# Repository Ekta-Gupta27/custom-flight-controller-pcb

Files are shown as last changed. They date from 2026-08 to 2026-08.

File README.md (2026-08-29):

# Custom Flight Controller PCB

A custom-designed flight controller PCB developed for embedded flight-control applications, integrating a high-performance STM32 MCU, multiple inertial and pressure sensors, CAN communication, external flash memory, power management, and dedicated FMU/IO interfaces.

The PCB and schematic were designed using **KiCad 9.0.7**.

---

## 📌 Project Overview

This project focuses on the design and development of a custom flight controller PCB with dedicated interfaces for sensors, communication peripherals, power, debugging, telemetry, PWM outputs, and RC input/output.

The design is divided into multiple functional sections:

- Main Flight Management Unit (FMU)
- IO controller
- IMU and pressure sensing
- CAN communication
- USB connectivity
- External SPI flash memory
- Power regulation
- Telemetry interfaces
- PWM and RC interfaces
- Debug/programming interfaces

---

## ✨ Key Features

- Custom PCB designed from schematic to board layout
- STM32F765VITx main flight controller MCU
- STM32F103CBTx dedicated IO controller
- Multiple onboard sensors
- CAN communication interface
- USB OTG interface
- External SPI flash memory
- Multiple UART interfaces
- I2C and SPI interfaces
- PWM output interface
- SBUS and PPM interfaces
- Debug/programming interface
- Dedicated GPS and telemetry connectors
- Onboard status/safety LEDs
- 3.3 V and 5 V power domains
- Multi-layer PCB layout
- Manufacturing-ready Gerber and drill files

---

## 🧠 Hardware Architecture

### Main Flight Controller

The primary processing unit is an **STM32F765VITx**.

The MCU provides the main processing and peripheral interfaces for the flight-control system, including:

- SPI
- I2C
- UART
- CAN
- Timer/PWM channels
- SWD debugging
- External GPIO

### IO Controller

A dedicated **STM32F103CBTx** is used for the IO section of the design.

The IO controller provides interfaces for:

- SBUS
- PPM
- PWM
- RC input/output
- Safety signals
- Status LEDs
- Debugging
- Additional UART interfaces

---

## 📡 Sensors

The design incorporates multiple sensors:

### ICM-42688-P

6-axis inertial measurement sensor connected through SPI.

### BMI270

6-axis inertial sensor with dedicated interrupt and SPI connections.

### ICP-20100

Pressure sensor connected through the I2C interface.

### BMM150

Magnetic sensor connected through the I2C interface.

---

## 🔌 Communication Interfaces

### CAN

CAN communication is implemented using the **SN65HVD230** transceiver with dedicated CANH and CANL connections and protection circuitry.

### USB

A USB OTG interface is provided along with USB ESD protection using **USBLC6-2P6**.

### UART / Telemetry

Dedicated connectors are provided for:

- TELEM1
- TELEM2
- TELEM3
- UART/I2C interface
- GPS
- FMU communication

### I2C

Multiple I2C buses are available for sensor and peripheral communication.

### SPI

Multiple SPI buses are routed to sensors, flash memory, and external interfaces.

---

## 💾 External Flash Memory

The board includes external SPI flash memory:

**W25Q128JVS**

The flash device is connected to the main MCU through SPI with a dedicated chip-select signal.

---

## ⚡ Power Management

The PCB contains dedicated power regulation and filtering circuitry for the different system power domains.

The design includes:

- 5 V input
- 3.3 V regulation
- USB 5 V input
- External 3.3 V supply
- Decoupling capacitors
- Ferrite filtering
- Power indication circuitry

The schematic includes regulators such as:

- LM1117DT-3.3
- TLV75733PDBVR

---

## 🎛️ Interfaces & Connectors

| Interface | Purpose |
|---|---|
| GPS_PORT | GPS connectivity |
| POWER | Power input |
| TELEM1 | Telemetry |
| TELEM2 | Telemetry |
| TELEM3 | Telemetry |
| CAN_CONN | CAN communication |
| USB_OTG | USB connectivity |
| DEBUG | Debug/programming |
| SPI_PORT | External SPI interface |
| I2C_PORT | External I2C interface |
| UART_I2CB | UART/I2C interface |
| FMU_PWM | PWM outputs |
| IO_PWM | IO PWM interface |
| SBUS_PORT | SBUS interface |
| SBUS_IN | SBUS input |
| PPM_PORT | PPM input |
| IO_DEBUG | IO debugging |

---

# 🖥️ PCB Design

## 3D View – Top

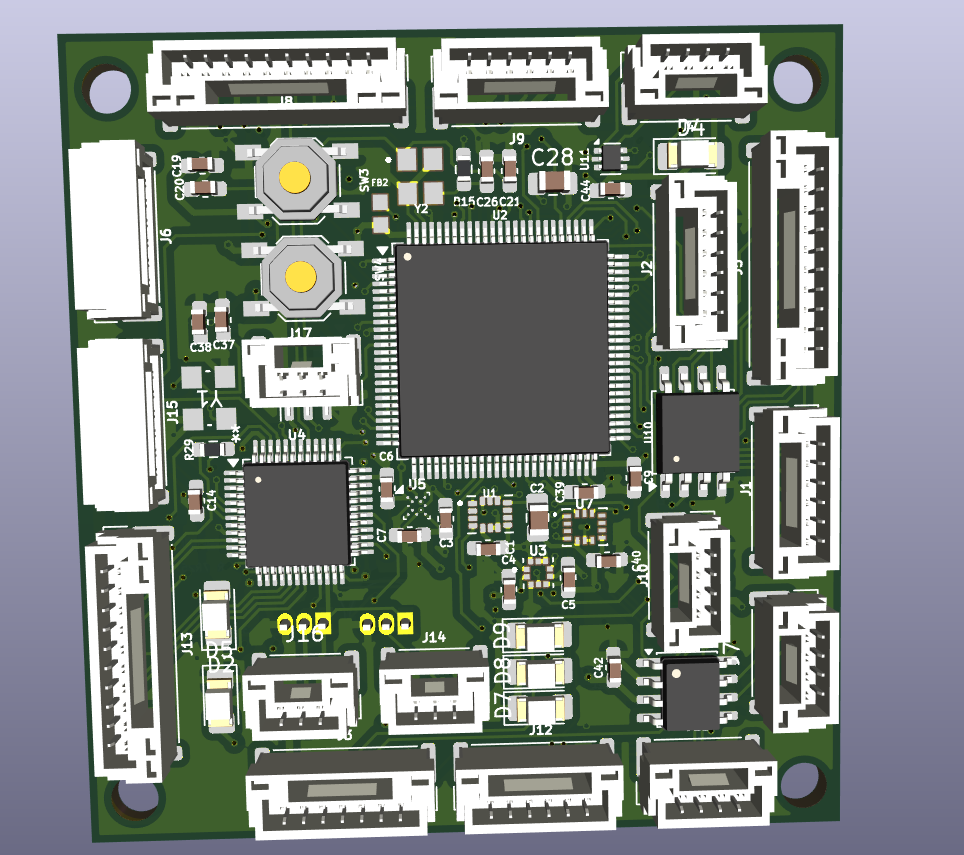
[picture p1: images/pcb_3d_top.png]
PCB 3D Top


## 3D View – Bottom

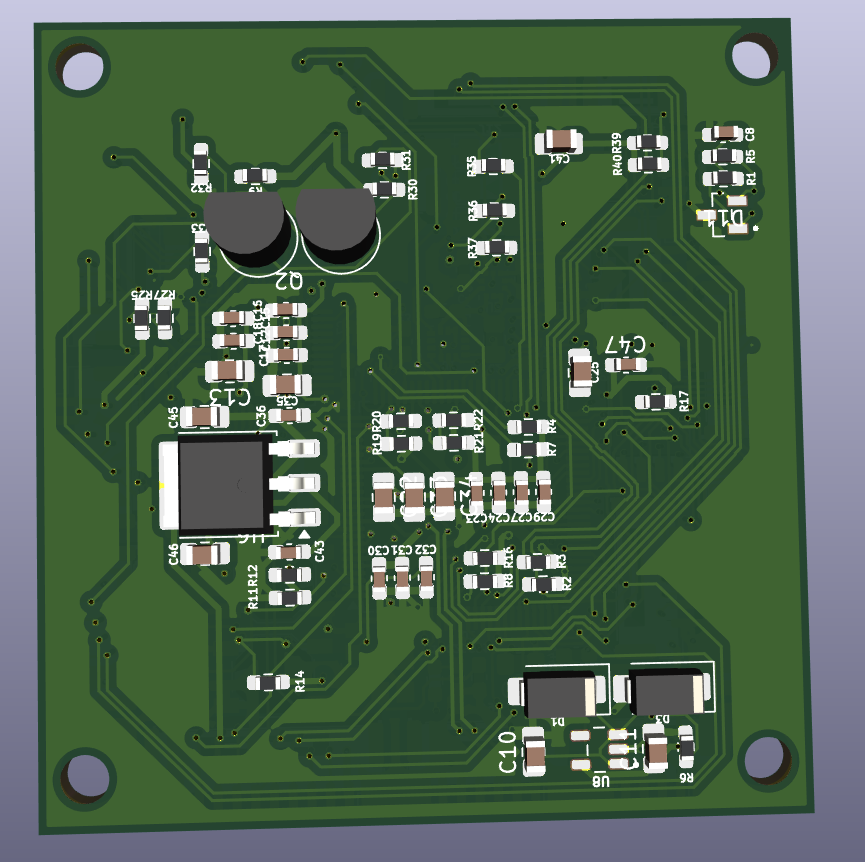
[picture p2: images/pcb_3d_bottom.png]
PCB 3D Bottom


## PCB Layout

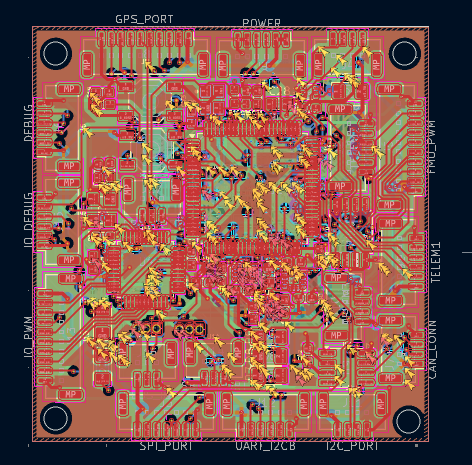
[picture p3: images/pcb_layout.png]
PCB Layout


---

# 📐 Schematic

The complete schematic is provided as a multi-page KiCad schematic covering:

1. FMU / MCU power and peripherals
2. USB and CAN
3. IMU and sensor interfaces
4. IO controller
5. Safety, RC and PWM interfaces

The PDF version is available in:

`docs/schematic.pdf`

---

# 🏭 Manufacturing Files

The `gerbers/` directory contains the manufacturing outputs generated from KiCad, including:

- Front and back copper
- Inner copper layers
- Front and back solder mask
- Front and back silkscreen
- Paste layers
- Board outline
- Drill files
- Gerber job file

These files can be supplied to a PCB manufacturer for fabrication.

---

# 📦 Bill of Materials

A Bill of Materials generated from the KiCad schematic is included in:

`manufacturing/BOM.csv`

The BOM contains information such as:

- Reference designators
- Component quantity
- Component value
- PCB footprint
- Datasheet information
- BOM exclusion fields

---

# 📁 Repository Structure

```text
Custom-FC-RAT/
│
├── README.md
├── custom_fc_rat.kicad_pro
│
├── schematic/
│   └── custom_fc_rat.kicad_sch
│
├── pcb/
│   └── custom_fc_rat.kicad_pcb
│
├── gerbers/
│   ├── *.gbl
│   ├── *.gtl
│   ├── *.gbs
│   ├── *.gts
│   ├── *.gbo
│   ├── *.gto
│   ├── *.gm1
│   ├── *.g1
│   ├── *.g2
│   ├── *.g3
│   ├── *.g4
│   ├── *.drl
│   └── *.gbrjob
│
├── manufacturing/
│   └── BOM.csv
│
├── images/
│   ├── pcb_3d_top.png
│   ├── pcb_3d_bottom.png
│   └── pcb_layout.png
│
└── docs/
    └── schematic.pdf
```

---

# 🛠️ Design Tools

| Tool | Purpose |
|---|---|
| KiCad 9.0.7 | Schematic & PCB design |
| KiCad 3D Viewer | PCB visualization |
| KiCad Gerber Generator | Manufacturing file generation |

---

# 🚀 Future Improvements

Possible future development includes:

- Hardware validation and bring-up documentation
- Flight-controller firmware integration
- Sensor calibration and validation
- Power integrity testing
- Communication interface testing
- EMI/EMC validation
- Flight testing
- PCB revisions based on hardware testing

---

# 📄 Documentation

The editable KiCad design files and schematic PDF are included so that the hardware design can be inspected and further developed.

---

# 👩‍💻 Author

**Ekta Gupta**

Custom PCB / Flight Controller Design Project

---

## ⭐ Project Status

**Hardware Design Completed**

Schematic, PCB layout, 3D visualization, BOM, and manufacturing files are included in this repository.

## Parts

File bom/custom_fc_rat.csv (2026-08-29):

Reference | Qty | Value | DNP | Exclude from BOM | Exclude from Board | Footprint | Datasheet
C1,C4,C5,C6,C7,C9,C12,C14,C15,C16,C17,C18,C19,C20,C23,C24,C27,C29,C30,C31,C32,C36,C39,C40,C42,C43,C44 | 27 | 0.1u |  |  |  | Capacitor_SMD:C_0603_1608Metric_Pad1.08x0.95mm_HandSolder | ~
C2,C10,C11 | 3 | 2.2u |  |  |  | Capacitor_SMD:C_0805_2012Metric_Pad1.18x1.45mm_HandSolder | ~
C3 | 1 | 10n |  |  |  | Capacitor_SMD:C_0603_1608Metric_Pad1.08x0.95mm_HandSolder | ~
C8 | 1 | 4.7n |  |  |  | Capacitor_SMD:C_0603_1608Metric_Pad1.08x0.95mm_HandSolder | ~
C13,C33,C34,C41 | 4 | 1u |  |  |  | Capacitor_SMD:C_0805_2012Metric_Pad1.18x1.45mm_HandSolder | ~
C21,C26 | 2 | 8pF |  |  |  | Capacitor_SMD:C_0603_1608Metric_Pad1.08x0.95mm_HandSolder | ~
C22,C35,C45,C46 | 4 | 10u |  |  |  | Capacitor_SMD:C_0805_2012Metric_Pad1.18x1.45mm_HandSolder | ~
C25,C28 | 2 | 2u2 |  |  |  | Capacitor_SMD:C_0805_2012Metric_Pad1.18x1.45mm_HandSolder | ~
C37,C38 | 2 | 18pF |  |  |  | Capacitor_SMD:C_0603_1608Metric_Pad1.08x0.95mm_HandSolder | ~
C47 | 1 | 1u |  |  |  | Capacitor_SMD:C_0603_1608Metric_Pad1.08x0.95mm_HandSolder | ~
D1,D3 | 2 | SS34 |  |  |  | Diode_SMD:D_SMA | https://www.vishay.com/docs/88751/ss32.pdf
D2,D4,D5,D7,D8,D9 | 6 | LED |  |  |  | LED_SMD:LED_1206_3216Metric_Pad1.42x1.75mm_HandSolder | ~
D11 | 1 | ESD2CANFD24DBZRQ1 |  |  |  | My_Footprints:SOT95P237X112-3N
FB2 | 1 | FerriteBead |  |  |  | My_Footprints:BEADC1608X95N | ~
J1 | 1 | TELEM1 |  |  |  | Connector_JST:JST_GH_BM06B-GHS-TBT_1x06-1MP_P1.25mm_Vertical | ~
J2 | 1 | TELEM2 |  |  |  | Connector_JST:JST_GH_BM06B-GHS-TBT_1x06-1MP_P1.25mm_Vertical | ~
J3 | 1 | SPI_PORT |  |  |  | Connector_JST:JST_GH_BM07B-GHS-TBT_1x07-1MP_P1.25mm_Vertical | ~
J4 | 1 | USB_OTG |  |  |  | Connector_JST:JST_GH_BM04B-GHS-TBT_1x04-1MP_P1.25mm_Vertical | ~
J5 | 1 | FMU_PWM |  |  |  | Connector_JST:JST_GH_BM10B-GHS-TBT_1x10-1MP_P1.25mm_Vertical | ~
J6 | 1 | DEBUG |  |  |  | Connector_JST:JST_GH_SM06B-GHS-TB_1x06-1MP_P1.25mm_Horizontal | ~
J7 | 1 | CAN_CONN |  |  |  | Connector_JST:JST_GH_BM04B-GHS-TBT_1x04-1MP_P1.25mm_Vertical | ~
J8 | 1 | GPS_PORT |  |  |  | Connector_JST:JST_GH_BM10B-GHS-TBT_1x10-1MP_P1.25mm_Vertical | ~
J9 | 1 | POWER |  |  |  | Connector_JST:JST_GH_BM06B-GHS-TBT_1x06-1MP_P1.25mm_Vertical | ~
J10 | 1 | TELEM3 |  |  |  | Connector_JST:JST_GH_BM04B-GHS-TBT_1x04-1MP_P1.25mm_Vertical | ~
J11 | 1 | I2C_PORT |  |  |  | Connector_JST:JST_GH_BM04B-GHS-TBT_1x04-1MP_P1.25mm_Vertical | ~
J12 | 1 | UART_I2CB |  |  |  | Connector_JST:JST_GH_BM06B-GHS-TBT_1x06-1MP_P1.25mm_Vertical | ~
J13 | 1 | IO_PWM |  |  |  | Connector_JST:JST_GH_BM10B-GHS-TBT_1x10-1MP_P1.25mm_Vertical | ~
J14 | 1 | SBUS_PORT |  |  |  | Connector_JST:JST_GH_BM03B-GHS-TBT_1x03-1MP_P1.25mm_Vertical | ~
J15 | 1 | IO_DEBUG |  |  |  | Connector_JST:JST_GH_SM06B-GHS-TB_1x06-1MP_P1.25mm_Horizontal | ~
J16 | 1 | SBUS_IN |  |  |  | Connector_JST:JST_GH_SM03B-GHS-TB_1x03-1MP_P1.25mm_Horizontal | ~
J17 | 1 | PPM_PORT |  |  |  | Connector_JST:JST_GH_BM03B-GHS-TBT_1x03-1MP_P1.25mm_Vertical | ~
Q1,Q2 | 2 | BC547 |  |  |  | Package_TO_SOT_THT:TO-92_Inline | https://www.onsemi.com/pub/Collateral/BC550-D.pdf
R1,R5 | 2 | 60R |  |  |  | Resistor_SMD:R_0603_1608Metric_Pad0.98x0.95mm_HandSolder | ~
R2,R3,R4,R7,R8,R16,R39,R40 | 8 | 4K7 |  |  |  | Resistor_SMD:R_0603_1608Metric_Pad0.98x0.95mm_HandSolder | ~
R6 | 1 | 1k5 |  |  |  | Resistor_SMD:R_0603_1608Metric_Pad0.98x0.95mm_HandSolder | ~
R9,R30 | 2 | 10k |  |  |  | Resistor_SMD:R_0603_1608Metric_Pad0.98x0.95mm_HandSolder | ~
R11,R14,R17,R25,R27 | 5 | 10K |  |  |  | Resistor_SMD:R_0603_1608Metric_Pad0.98x0.95mm_HandSolder | ~
R12 | 1 | 22R |  |  |  | Resistor_SMD:R_0603_1608Metric_Pad0.98x0.95mm_HandSolder | ~
R15 | 1 | 47R |  |  |  | Resistor_SMD:R_0603_1608Metric_Pad0.98x0.95mm_HandSolder | ~
R19,R20,R21,R22 | 4 | 5K1 |  |  |  | Resistor_SMD:R_0603_1608Metric_Pad0.98x0.95mm_HandSolder | ~
R29 | 1 | 150R |  |  |  | Resistor_SMD:R_0603_1608Metric_Pad0.98x0.95mm_HandSolder | ~
R31 | 1 | 4.7k |  |  |  | Resistor_SMD:R_0603_1608Metric_Pad0.98x0.95mm_HandSolder | ~
R32,R33,R35,R36,R37 | 5 | 220R |  |  |  | Resistor_SMD:R_0603_1608Metric_Pad0.98x0.95mm_HandSolder | ~
SW3,SW4 | 2 | SW_Push |  |  |  | Button_Switch_SMD:SW_SPST_TL3342 | ~
U1 | 1 | ICM-42688-P |  |  |  | My_Footprints:PQFN50P300X250X97-14N
U2 | 1 | STM32F765VITx |  |  |  | Package_QFP:LQFP-100_14x14mm_P0.5mm | https://www.st.com/resource/en/datasheet/stm32f765vi.pdf
U3 | 1 | ICP-20100 |  |  |  | My_Footprints:PQFN50P200X200X85-10N
U4 | 1 | STM32F103CBTx |  |  |  | Package_QFP:LQFP-48_7x7mm_P0.5mm | https://www.st.com/resource/en/datasheet/stm32f103cb.pdf
U5 | 1 | BMM150 |  |  |  | Package_CSP:WLCSP-12_1.56x1.56mm_P0.4mm | https://www.mouser.com/datasheet/2/783/BST-BMM150-DS001-01-786480.pdf
U6 | 1 | LM1117DT-3.3 |  |  |  | Package_TO_SOT_SMD:TO-252-3_TabPin2 | http://www.ti.com/lit/ds/symlink/lm1117.pdf
U7 | 1 | BMI270 |  |  |  | My_Footprints:XDCR_BMI270
U8 | 1 | TLV75733PDBVR |  |  |  | My_Footprints:SOT95P280X145-5N
U9 | 1 | SN65HVD230 |  |  |  | Package_SO:SOIC-8_3.9x4.9mm_P1.27mm | http://www.ti.com/lit/ds/symlink/sn65hvd230.pdf
U10 | 1 | W25Q128JVS |  |  |  | Package_SO:SOIC-8_5.3x5.3mm_P1.27mm | https://www.winbond.com/resource-files/w25q128jv_dtr%20revc%2003272018%20plus.pdf
U11 | 1 | USBLC6-2P6 |  |  |  | Package_TO_SOT_SMD:SOT-666 | https://www.st.com/resource/en/datasheet/usblc6-2.pdf
Y1 | 1 | Crystal_GND24 |  |  |  | My_Footprints:YSX321SL_YXC | ~
Y2 | 1 | Crystal_GND24 |  |  |  | My_Footprints:OSC_X322516MLB4SI | ~

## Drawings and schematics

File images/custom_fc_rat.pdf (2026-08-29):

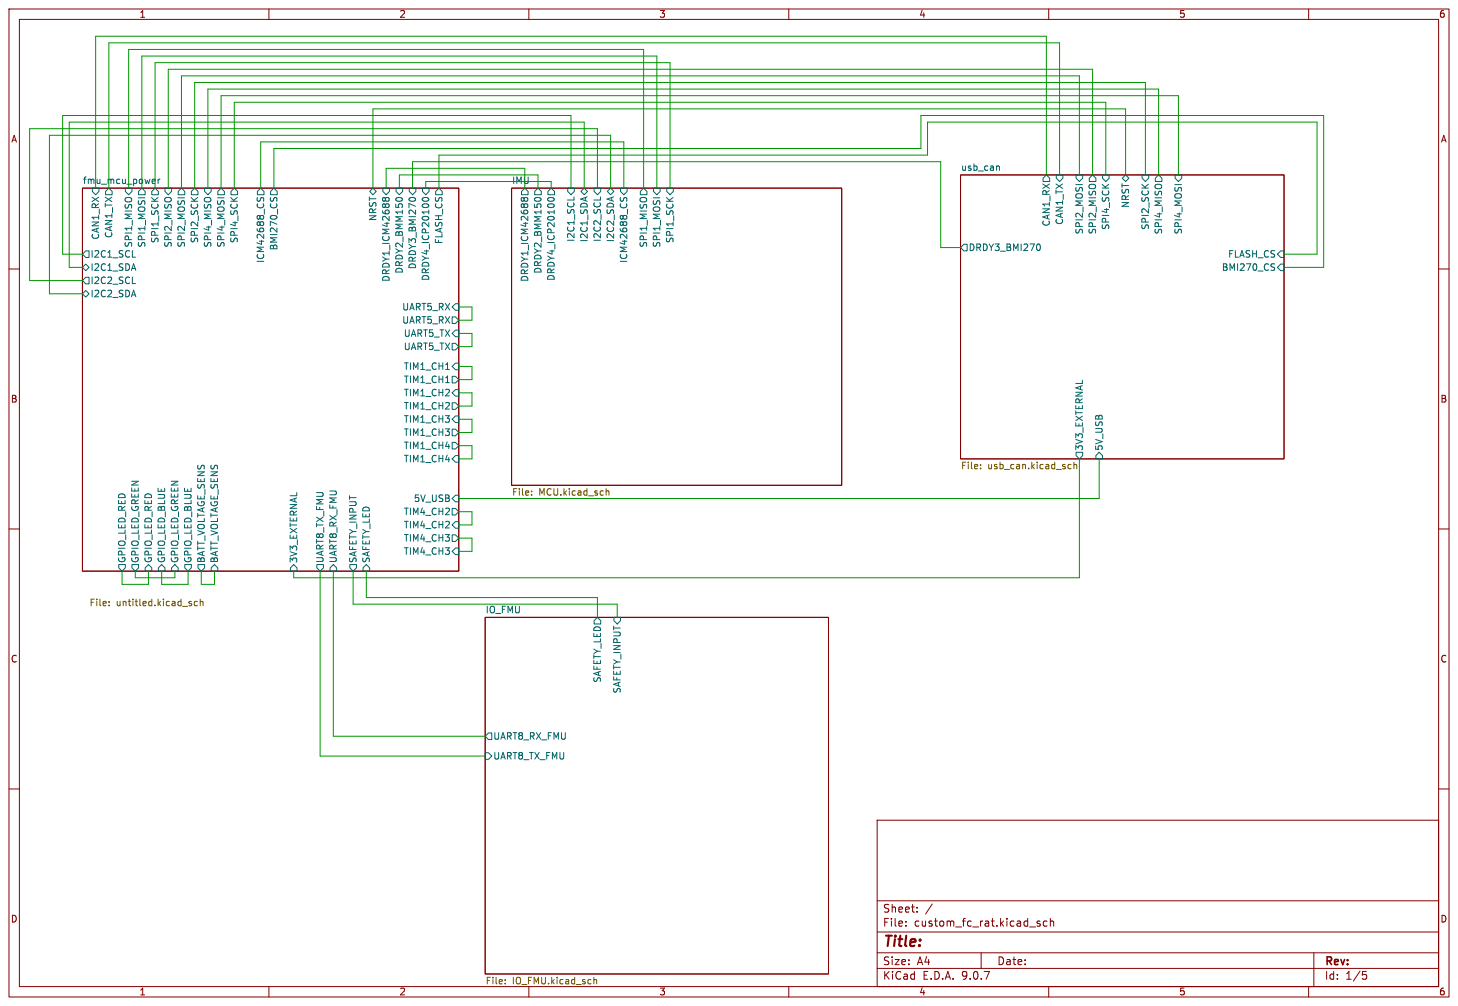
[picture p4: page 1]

Id: 1/5 Title: File: custom_fc_rat.kicad_sch Sheet: / SAFETY_INPUT SAFETY_LED

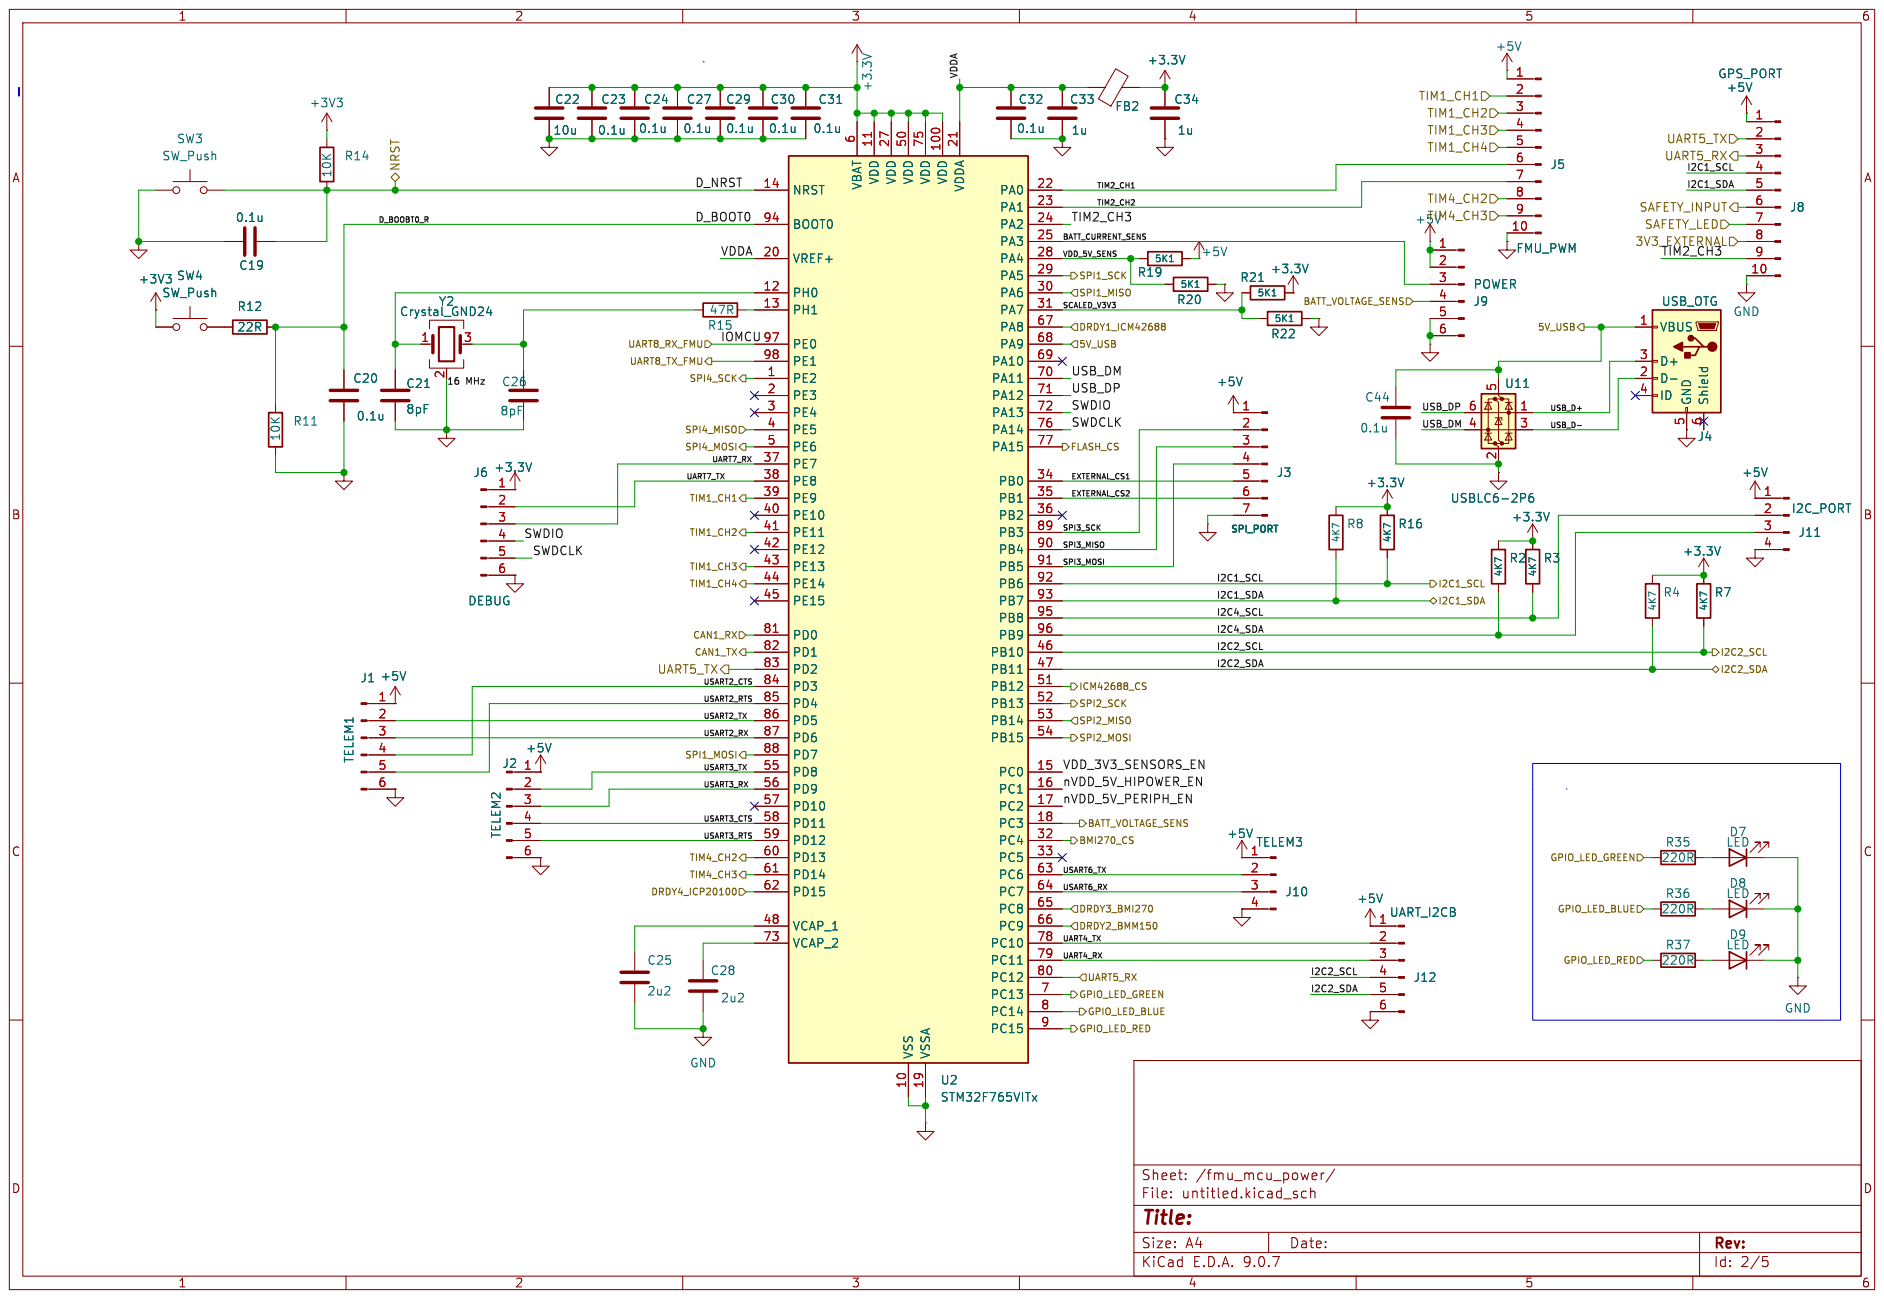
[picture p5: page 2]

6 VDD 11 VDD 27 VDD 50 VSS 10 VDD 75 VSSA 19 VDD 100 VDDA 21 PA0 22 PA1 23 PA2 24 PA3 25 PA4 28 PA5 29 PA6 30 PA7 31 PA8 67 PA9 68 PA10 69 PA11 70 PA12 71 PA13 72 PA14 76 PA15 77 PB0 34 PB1 35 PB2 36 PB3 89 PB4 90 PB5 91 PB6 92 PB7 93 PB8 95 PB9 96 PB10 46 PB11 47 PB12 51 PB13 52 PB14 53 PB15 54 PC0 15 PC1 16 PC2 17 PC3 18 PC4 32 PC5 33 PC6 63 PC7 64 PC8 65 PC9 66 PC10 78 PC11 79 PC12 80 PC13 7 PC14 8 PC15 9 U2STM32F765VITx GND

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

Id: 2/5 Title: File: untitled.kicad_sch Sheet: /fmu_mcu_power/

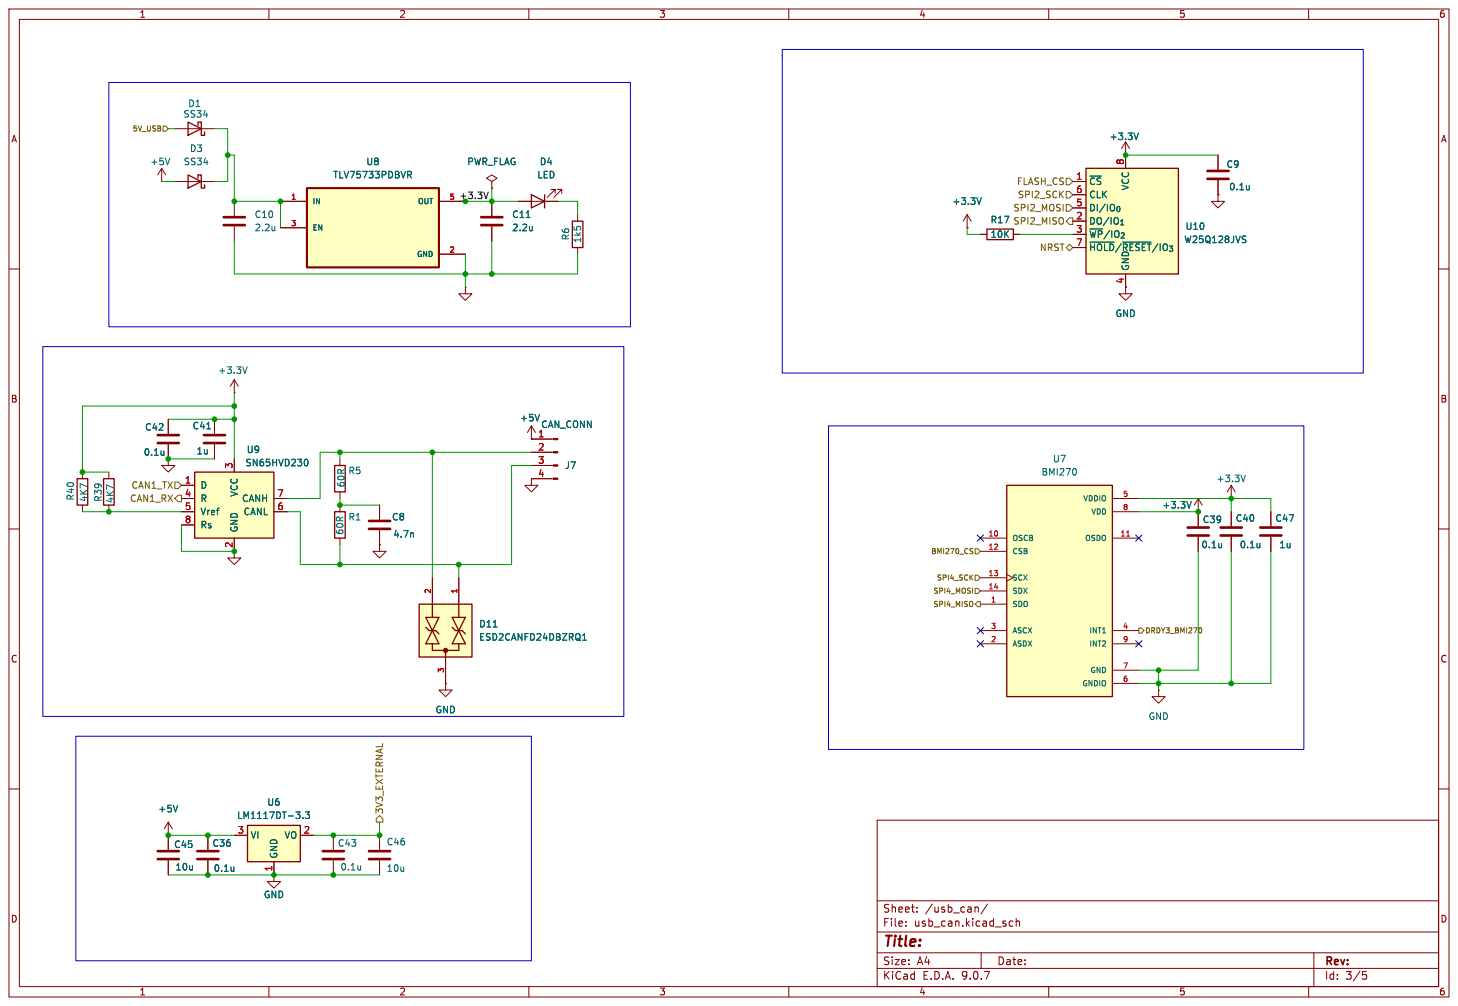
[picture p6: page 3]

Id: 3/5 Title: File: usb_can.kicad_sch Sheet: /usb_can/

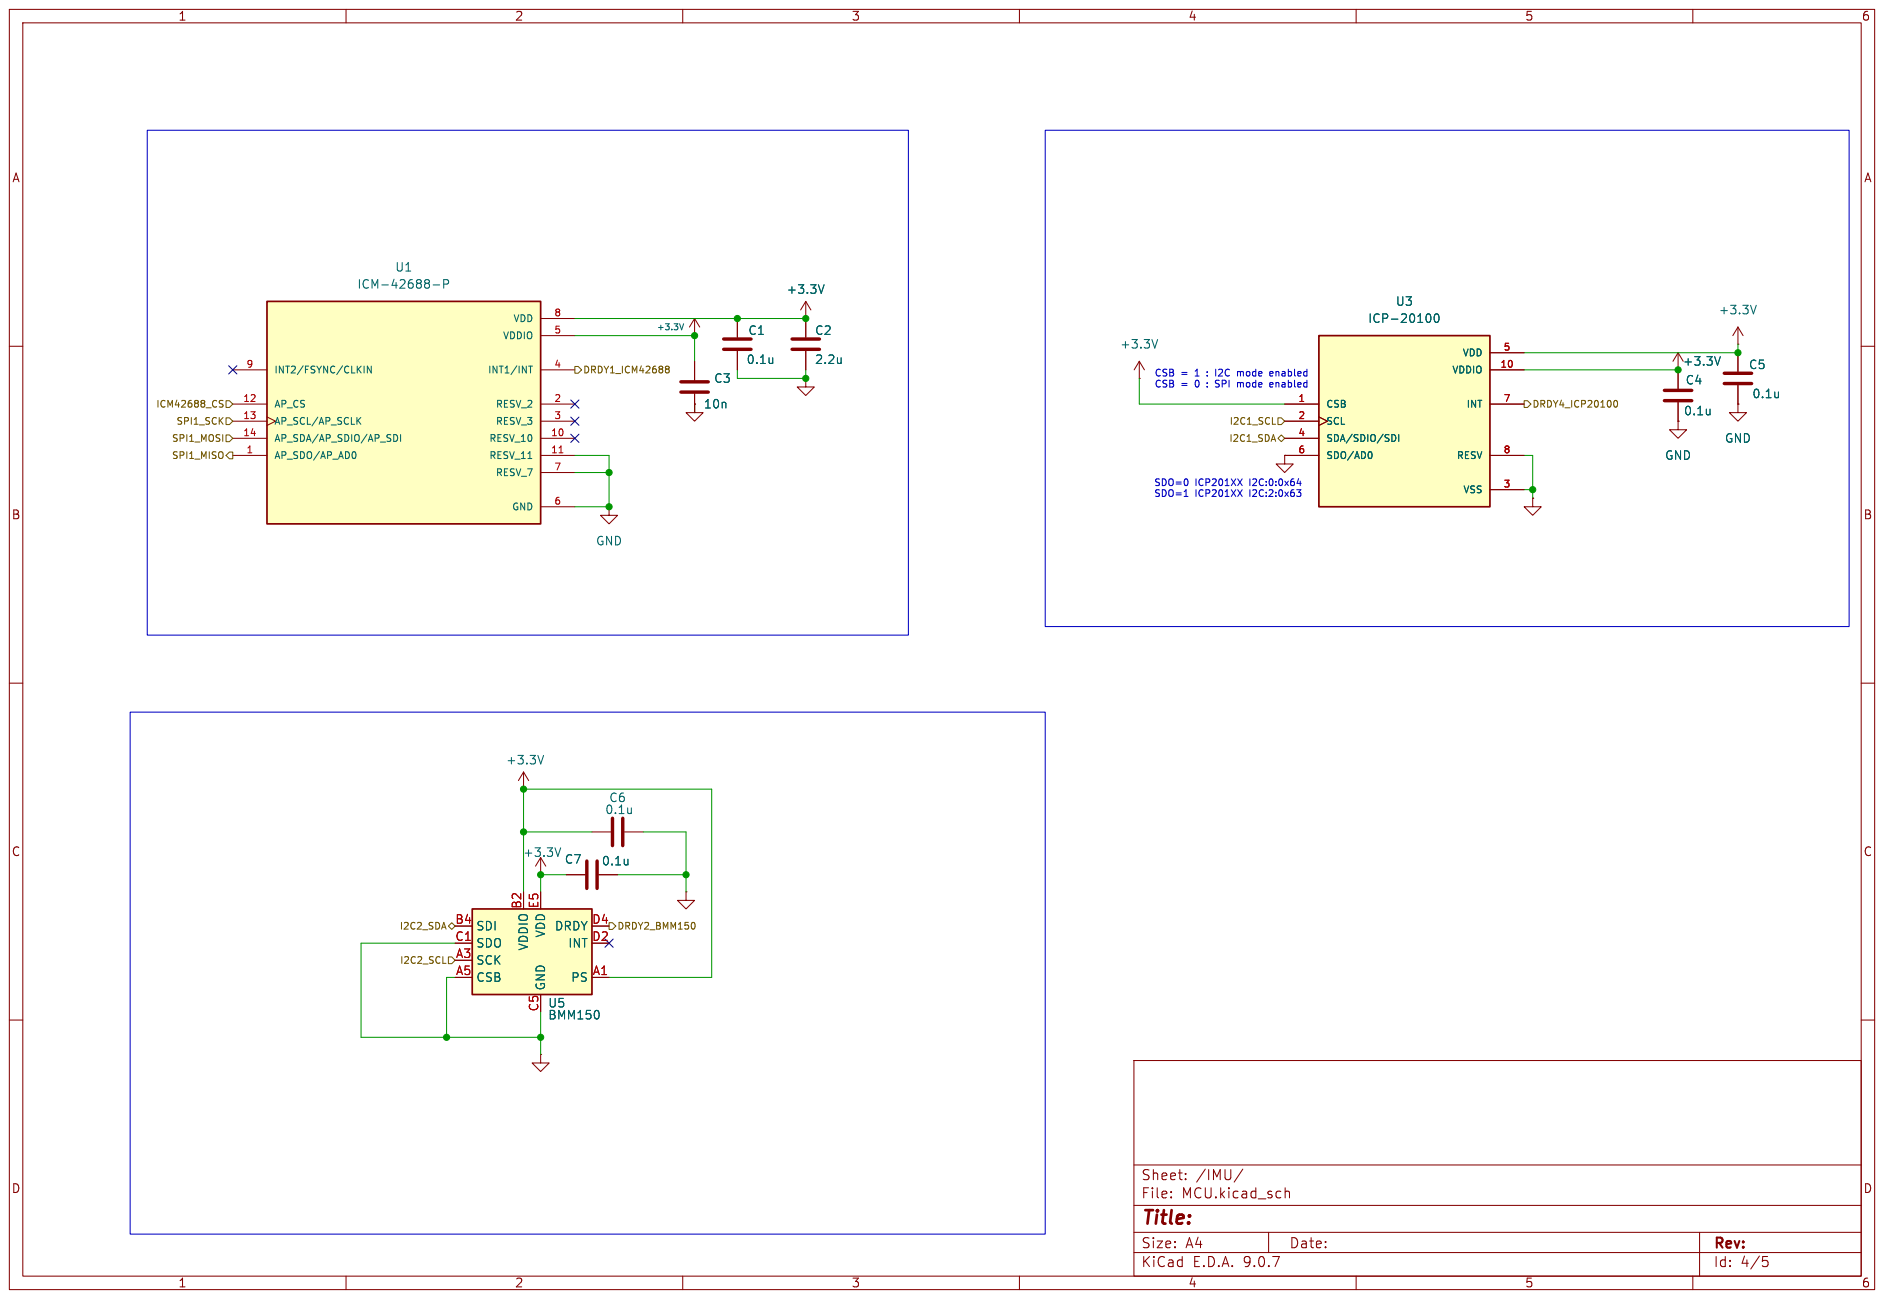
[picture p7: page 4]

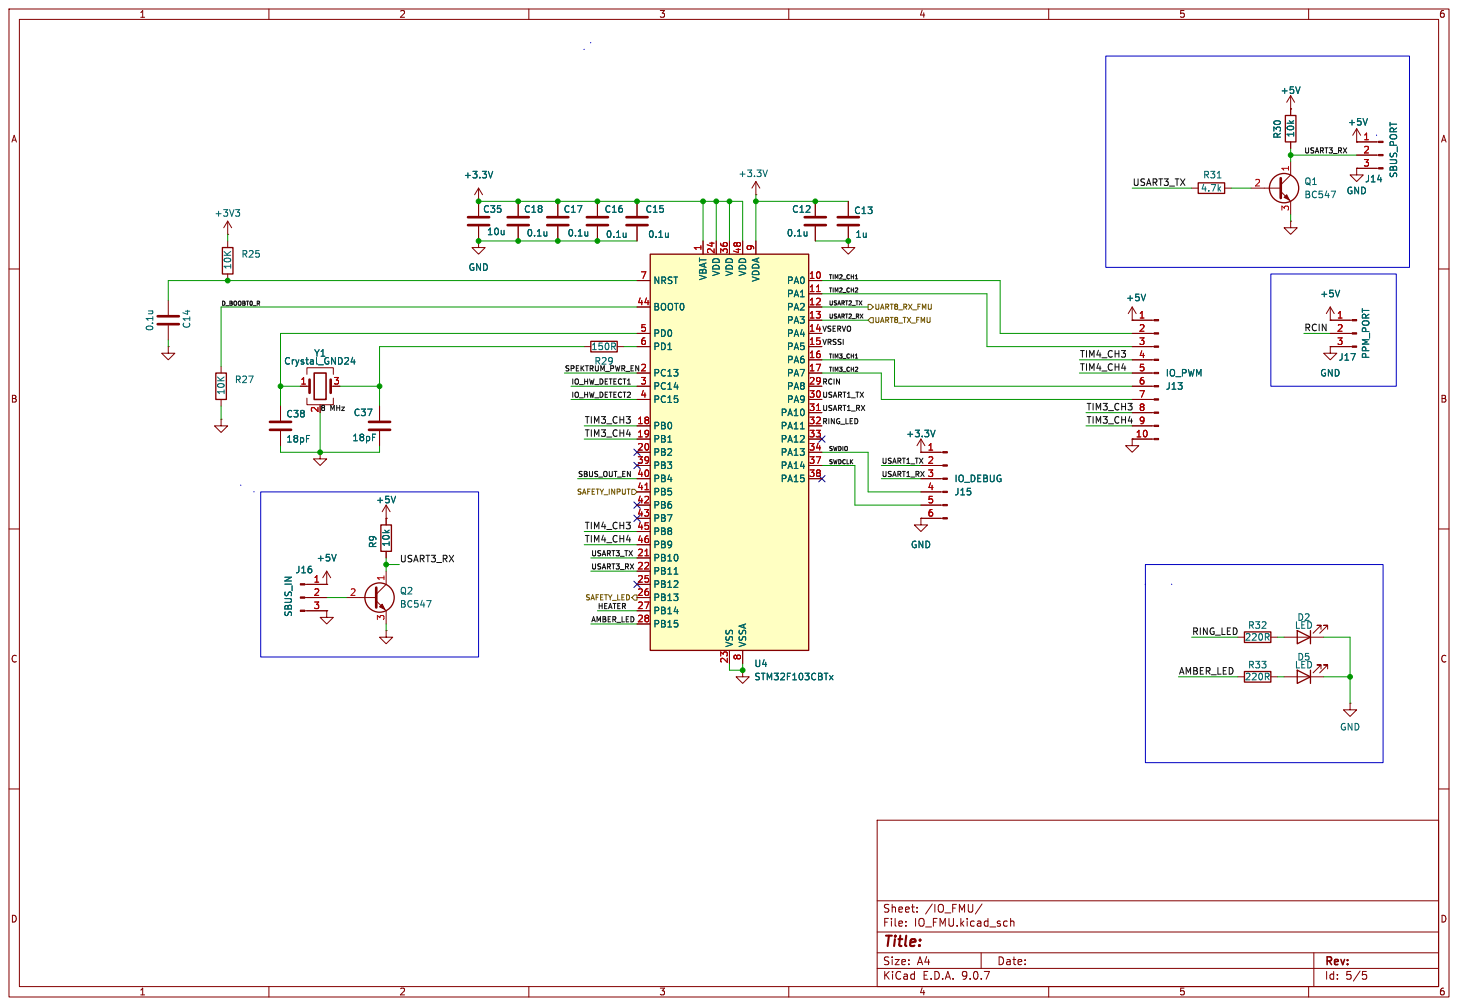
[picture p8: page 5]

1 VDD 24 VDD 36 VSS 23 VDD 48 VSSA

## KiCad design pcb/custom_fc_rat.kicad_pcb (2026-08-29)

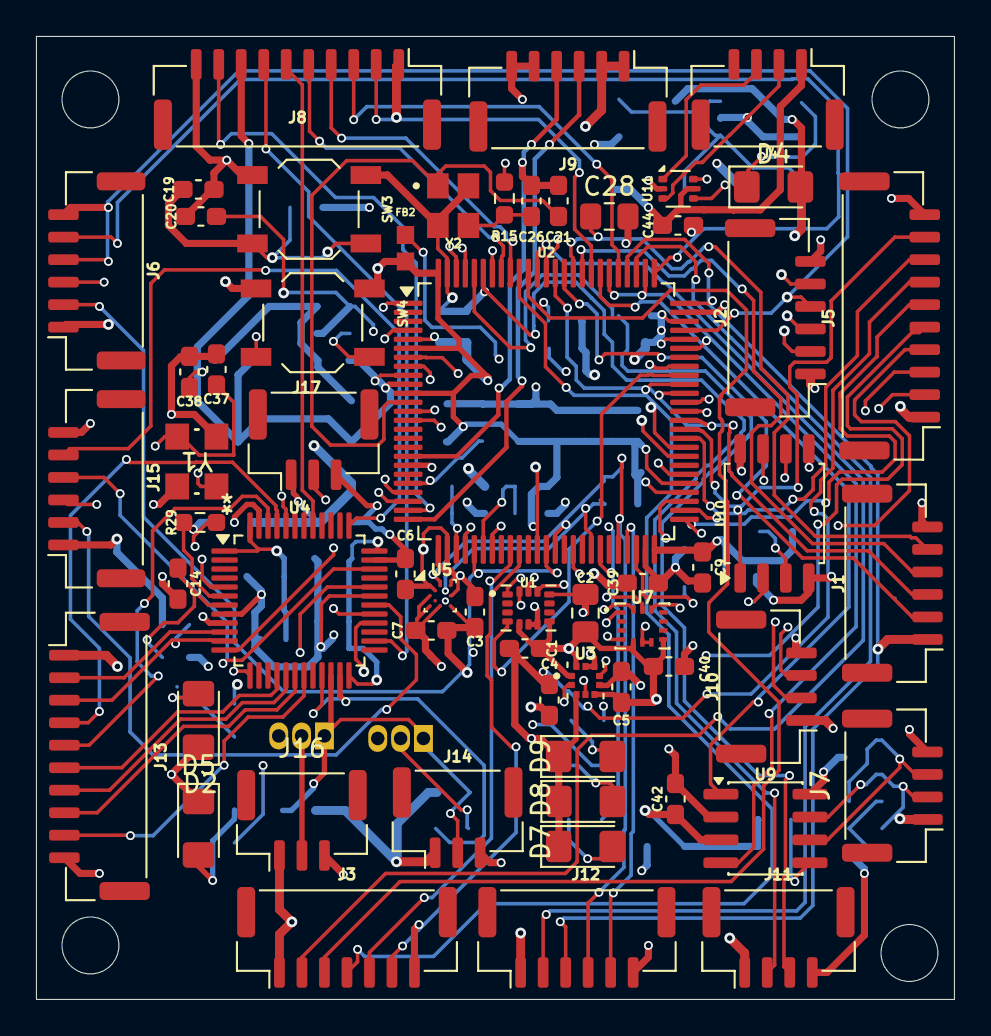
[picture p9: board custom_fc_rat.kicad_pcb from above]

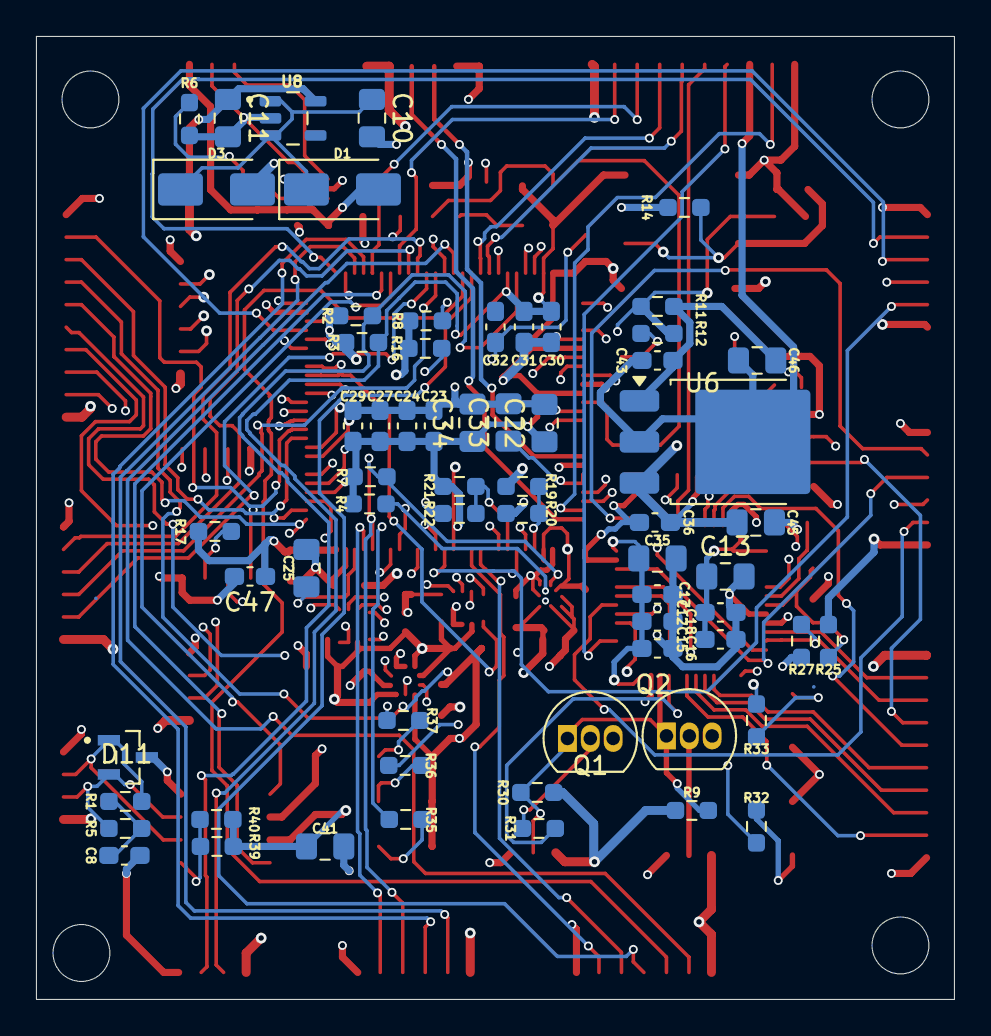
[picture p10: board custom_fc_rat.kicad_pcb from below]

Board: 6 copper layers, 51.0 x 53.5 mm, 122 parts (63 on the bottom side), 121 nets.

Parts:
C1, C4, C5, C6, C7, C9, C12, C14, C15, C16, C17, C18, C19, C20, C23, C24, C27, C29, C30, C31, C32, C36, C39, C40, C42, C43, C44: 0.1u; C_0603_1608Metric_Pad1.08x0.95mm_HandSolder
C2, C10, C11: 2.2u; C_0805_2012Metric_Pad1.18x1.45mm_HandSolder
C3: 10n; C_0603_1608Metric_Pad1.08x0.95mm_HandSolder
C8: 4.7n; C_0603_1608Metric_Pad1.08x0.95mm_HandSolder
C13, C33, C34, C41: 1u; C_0805_2012Metric_Pad1.18x1.45mm_HandSolder
C21, C26: 8pF; C_0603_1608Metric_Pad1.08x0.95mm_HandSolder
C22, C35, C45, C46: 10u; C_0805_2012Metric_Pad1.18x1.45mm_HandSolder
C25, C28: 2u2; C_0805_2012Metric_Pad1.18x1.45mm_HandSolder
C37, C38: 18pF; C_0603_1608Metric_Pad1.08x0.95mm_HandSolder
C47: 1u; C_0603_1608Metric_Pad1.08x0.95mm_HandSolder
D1, D3: SS34; D_SMA
D2, D4, D5, D7, D8, D9: LED; LED_1206_3216Metric_Pad1.42x1.75mm_HandSolder
D11: ESD2CANFD24DBZRQ1; SOT95P237X112-3N
FB2: FerriteBead; BEADC1608X95N
J1: TELEM1; JST_GH_BM06B-GHS-TBT_1x06-1MP_P1.25mm_Vertical
J2: TELEM2; JST_GH_BM06B-GHS-TBT_1x06-1MP_P1.25mm_Vertical
J3: SPI_PORT; JST_GH_BM07B-GHS-TBT_1x07-1MP_P1.25mm_Vertical
J4: USB_OTG; JST_GH_BM04B-GHS-TBT_1x04-1MP_P1.25mm_Vertical
J5: FMU_PWM; JST_GH_BM10B-GHS-TBT_1x10-1MP_P1.25mm_Vertical
J6: DEBUG; JST_GH_SM06B-GHS-TB_1x06-1MP_P1.25mm_Horizontal
J7: CAN_CONN; JST_GH_BM04B-GHS-TBT_1x04-1MP_P1.25mm_Vertical
J8: GPS_PORT; JST_GH_BM10B-GHS-TBT_1x10-1MP_P1.25mm_Vertical
J9: POWER; JST_GH_BM06B-GHS-TBT_1x06-1MP_P1.25mm_Vertical
J10: TELEM3; JST_GH_BM04B-GHS-TBT_1x04-1MP_P1.25mm_Vertical
J11: I2C_PORT; JST_GH_BM04B-GHS-TBT_1x04-1MP_P1.25mm_Vertical
J12: UART_I2CB; JST_GH_BM06B-GHS-TBT_1x06-1MP_P1.25mm_Vertical
J13: IO_PWM; JST_GH_BM10B-GHS-TBT_1x10-1MP_P1.25mm_Vertical
J14: SBUS_PORT; JST_GH_BM03B-GHS-TBT_1x03-1MP_P1.25mm_Vertical
J15: IO_DEBUG; JST_GH_SM06B-GHS-TB_1x06-1MP_P1.25mm_Horizontal
J16: SBUS_IN; JST_GH_BM03B-GHS-TBT_1x03-1MP_P1.25mm_Vertical
J17: PPM_PORT; JST_GH_BM03B-GHS-TBT_1x03-1MP_P1.25mm_Vertical
Q1, Q2: BC547; TO-92_Inline
R1, R5: 60R; R_0603_1608Metric_Pad0.98x0.95mm_HandSolder
R2, R3, R4, R7, R8, R16, R39, R40: 4K7; R_0603_1608Metric_Pad0.98x0.95mm_HandSolder
R6: 1k5; R_0603_1608Metric_Pad0.98x0.95mm_HandSolder
R9, R30: 10k; R_0603_1608Metric_Pad0.98x0.95mm_HandSolder
R11, R14, R17, R25, R27: 10K; R_0603_1608Metric_Pad0.98x0.95mm_HandSolder
R12: 22R; R_0603_1608Metric_Pad0.98x0.95mm_HandSolder
R15: 47R; R_0603_1608Metric_Pad0.98x0.95mm_HandSolder
R19, R20, R21, R22: 5K1; R_0603_1608Metric_Pad0.98x0.95mm_HandSolder
R29: 150R; R_0603_1608Metric_Pad0.98x0.95mm_HandSolder
R31: 4.7k; R_0603_1608Metric_Pad0.98x0.95mm_HandSolder
R32, R33, R35, R36, R37: 220R; R_0603_1608Metric_Pad0.98x0.95mm_HandSolder
SW3, SW4: SW_Push; SW_SPST_TL3342
U1: ICM-42688-P; PQFN50P300X250X97-14N
U2: STM32F765VITx; LQFP-100_14x14mm_P0.5mm
U3: ICP-20100; PQFN50P200X200X85-10N
U4: STM32F103CBTx; LQFP-48_7x7mm_P0.5mm
U5: BMM150; WLCSP-12_1.56x1.56mm_P0.4mm
U6: LM1117DT-3.3; TO-252-3_TabPin2
U7: BMI270; XDCR_BMI270
U8: TLV75733PDBVR; SOT95P280X145-5N
U9: SN65HVD230; SOIC-8_3.9x4.9mm_P1.27mm
U10: W25Q128JVS; SOIC-8_5.3x5.3mm_P1.27mm
U11: USBLC6-2P6; SOT-666
Y1: Crystal_GND24; YSX321SL_YXC
Y2: Crystal_GND24; OSC_X322516MLB4SI

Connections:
+3.3V: C1.1, C2.1, C3.1, C4.1, C5.1, C6.1, C7.1, C9.1, C11.1, C12.1, C13.1, C15.1, C16.1, C17.1, C18.1, C22.1, C23.1, C24.1, C27.1, C29.1, C30.1, C31.1, C34.1, C35.1, C39.1, C40.1, C41.1, C42.1, C47.1, D4.2 (A), FB2.2, J6.1, J15.1, R2.1, R3.1, R4.1, R7.1, R8.1, R14.1, R16.1, R17.1, R21.2, R25.1, R39.1, R40.1, SW4.1, U1.5 (VDDIO), U1.8 (VDD), U2.6 (VBAT), U2.11 (VDD), U2.27 (VDD), U2.50 (VDD), U2.75 (VDD), U2.100 (VDD), U3.1 (CSB), U3.5 (VDD), U3.10 (VDDIO), U4.1 (VBAT), U4.9 (VDDA), U4.24 (VDD), U4.36 (VDD), U4.48 (VDD), U5.A1 (PS), U5.B2 (VDDIO), U5.E5 (VDD), U7.5 (VDDIO), U7.8 (VDD), U8.5 (OUT), U9.3 (VCC), U10.8 (VCC)
+5V: C36.2, C45.1, D3.2 (A), J1.1, J2.1, J3.1, J5.1, J7.1, J8.1, J9.1, J9.2, J10.1, J11.1, J12.1, J13.1, J14.1, J16.1, J17.1, R9.1, R19.2, R30.1, U6.3 (VI)
/IMU/DRDY1_ICM42688: U1.4 (INT1/INT), U2.67 (PA8)
/IMU/DRDY2_BMM150: U2.66 (PC9), U5.D4 (DRDY)
/IMU/DRDY4_ICP20100: U2.62 (PD15), U3.7 (INT)
/IMU/ICM42688_CS: U1.12 (AP_CS), U2.51 (PB12)
/IMU/SPI1_MISO: U1.1 (AP_SDO/AP_AD0), U2.30 (PA6)
/IMU/SPI1_MOSI: U1.14 (AP_SDA/AP_SDIO/AP_SDI), U2.88 (PD7)
/IMU/SPI1_SCK: U1.13 (AP_SCL/AP_SCLK), U2.29 (PA5)
/IO_FMU/AMBER_LED: R33.1, U4.28 (PB15)
/IO_FMU/D_BOOBT0_R: R27.1, U4.44 (BOOT0)
/IO_FMU/RCIN: J17.2, U4.29 (PA8)
/IO_FMU/RING_LED: R32.1, U4.32 (PA11)
/IO_FMU/SAFETY_INPUT: J8.6, U4.41 (PB5)
/IO_FMU/SAFETY_LED: J8.7, U4.26 (PB13)
/IO_FMU/SWDCLK: J15.5, U4.37 (PA14)
/IO_FMU/SWDIO: J15.4, U4.34 (PA13)
/IO_FMU/TIM2_CH1: J13.2, U4.10 (PA0)
/IO_FMU/TIM2_CH2: J13.3, U4.11 (PA1)
/IO_FMU/TIM3_CH1: J13.6, U4.16 (PA6)
/IO_FMU/TIM3_CH2: J13.7, U4.17 (PA7)
/IO_FMU/TIM3_CH3: J13.8, U4.18 (PB0)
/IO_FMU/TIM3_CH4: J13.9, U4.19 (PB1)
/IO_FMU/TIM4_CH3: J13.4, U4.45 (PB8)
/IO_FMU/TIM4_CH4: J13.5, U4.46 (PB9)
/IO_FMU/USART1_RX: J15.3, U4.31 (PA10)
/IO_FMU/USART1_TX: J15.2, U4.30 (PA9)
/IO_FMU/USART2_RX: U2.98 (PE1), U4.13 (PA3)
/IO_FMU/USART2_TX: U2.97 (PE0), U4.12 (PA2)
/IO_FMU/USART3_RX: J14.2, Q1.1 (C), Q2.1 (C), R9.2, R30.2, U4.22 (PB11)
/IO_FMU/USART3_TX: R31.1, U4.21 (PB10)
/fmu_mcu_power/3V3_EXTERNAL: C43.1, C46.1, J8.8, U6.2 (VO)
/fmu_mcu_power/5V_USB: C44.1, D1.2 (A), J4.1 (VBUS), U2.68 (PA9), U11.5 (VBUS)
/fmu_mcu_power/BATT_CURRENT_SENS: J9.3, U2.25 (PA3)
/fmu_mcu_power/BATT_VOLTAGE_SENS: J9.4, U2.18 (PC3)
/fmu_mcu_power/BMI270_CS: U2.32 (PC4), U7.12 (CSB)
/fmu_mcu_power/CAN1_RX: U2.81 (PD0), U9.4 (R)
/fmu_mcu_power/CAN1_TX: U2.82 (PD1), U9.1 (D)
/fmu_mcu_power/DRDY3_BMI270: U2.65 (PC8), U7.4 (INT1)
/fmu_mcu_power/D_BOOBT0_R: C20.1, R11.1, R12.2, U2.94 (BOOT0)
/fmu_mcu_power/D_NRST: C19.2, R14.2, SW3.2, U2.14 (NRST), U10.7 (~HOLD/~RESET/IO_{3})
/fmu_mcu_power/EXTERNAL_CS1: J3.5, U2.34 (PB0)
/fmu_mcu_power/EXTERNAL_CS2: J3.6, U2.35 (PB1)
/fmu_mcu_power/FLASH_CS: U2.77 (PA15), U10.1 (~CS)
/fmu_mcu_power/GPIO_LED_BLUE: R36.1, U2.8 (PC14)
/fmu_mcu_power/GPIO_LED_GREEN: R35.1, U2.7 (PC13)
/fmu_mcu_power/GPIO_LED_RED: R37.1, U2.9 (PC15)
/fmu_mcu_power/I2C1_SCL: J8.4, R16.2, U2.92 (PB6), U3.2 (SCL)
/fmu_mcu_power/I2C1_SDA: J8.5, R8.2, U2.93 (PB7), U3.4 (SDA/SDIO/SDI)
/fmu_mcu_power/I2C2_SCL: J12.4, R7.2, U2.46 (PB10), U5.A3 (SCK)
/fmu_mcu_power/I2C2_SDA: J12.5, R4.2, U2.47 (PB11), U5.B4 (SDI)
/fmu_mcu_power/I2C4_SCL: J11.2, R3.2, U2.95 (PB8)
/fmu_mcu_power/I2C4_SDA: J11.3, R2.2, U2.96 (PB9)
/fmu_mcu_power/SCALED_V3V3: R21.1, R22.1, U2.31 (PA7)
/fmu_mcu_power/SPI2_MISO: U2.53 (PB14), U10.2 (DO/IO_{1})
/fmu_mcu_power/SPI2_MOSI: U2.54 (PB15), U10.5 (DI/IO_{0})
/fmu_mcu_power/SPI2_SCK: U2.52 (PB13), U10.6 (CLK)
/fmu_mcu_power/SPI3_MISO: J3.3, U2.90 (PB4)
/fmu_mcu_power/SPI3_MOSI: J3.4, U2.91 (PB5)
/fmu_mcu_power/SPI3_SCK: J3.2, U2.89 (PB3)
/fmu_mcu_power/SPI4_MISO: U2.4 (PE5), U7.1 (SDO)
/fmu_mcu_power/SPI4_MOSI: U2.5 (PE6), U7.14 (SDX)
/fmu_mcu_power/SPI4_SCK: U2.1 (PE2), U7.13 (SCX)
/fmu_mcu_power/SWDCLK: J6.5, U2.76 (PA14)
/fmu_mcu_power/SWDIO: J6.4, U2.72 (PA13)
/fmu_mcu_power/TIM1_CH1: J5.2, U2.39 (PE9)
/fmu_mcu_power/TIM1_CH2: J5.3, U2.41 (PE11)
/fmu_mcu_power/TIM1_CH3: J5.4, U2.43 (PE13)
/fmu_mcu_power/TIM1_CH4: J5.5, U2.44 (PE14)
/fmu_mcu_power/TIM2_CH1: J5.6, U2.22 (PA0)
/fmu_mcu_power/TIM2_CH2: J5.7, U2.23 (PA1)
/fmu_mcu_power/TIM2_CH3: J8.9, U2.24 (PA2)
/fmu_mcu_power/TIM4_CH2: J5.8, U2.60 (PD13)
/fmu_mcu_power/TIM4_CH3: J5.9, U2.61 (PD14)
/fmu_mcu_power/UART4_RX: J12.3, U2.79 (PC11)
/fmu_mcu_power/UART4_TX: J12.2, U2.78 (PC10)
/fmu_mcu_power/UART5_RX: J8.3, U2.80 (PC12)
/fmu_mcu_power/UART5_TX: J8.2, U2.83 (PD2)
/fmu_mcu_power/UART7_RX: J6.3, U2.37 (PE7)
/fmu_mcu_power/UART7_TX: J6.2, U2.38 (PE8)
/fmu_mcu_power/USART2_CTS: J1.4, U2.84 (PD3)
/fmu_mcu_power/USART2_RTS: J1.5, U2.85 (PD4)
/fmu_mcu_power/USART2_RX: J1.3, U2.87 (PD6)
/fmu_mcu_power/USART2_TX: J1.2, U2.86 (PD5)
/fmu_mcu_power/USART3_CTS: J2.4, U2.58 (PD11)
/fmu_mcu_power/USART3_RTS: J2.5, U2.59 (PD12)
/fmu_mcu_power/USART3_RX: J2.3, U2.56 (PD9)
/fmu_mcu_power/USART3_TX: J2.2, U2.55 (PD8)
/fmu_mcu_power/USART6_RX: J10.3, U2.64 (PC7)
/fmu_mcu_power/USART6_TX: J10.2, U2.63 (PC6)
/fmu_mcu_power/USB_D+: J4.3 (D+), U11.1 (I/O1)
/fmu_mcu_power/USB_D-: J4.2 (D-), U11.3 (I/O2)
/fmu_mcu_power/USB_DM: U2.70 (PA11), U11.4 (I/O2)
/fmu_mcu_power/USB_DP: U2.71 (PA12), U11.6 (I/O1)
/fmu_mcu_power/VDDA: C32.1, C33.1, FB2.1, U2.20 (VREF+), U2.21 (VDDA)
/fmu_mcu_power/VDD_5V_SENS: R19.1, R20.1, U2.28 (PA4)
GND: C1.2, C2.2, C3.2, C4.2, C5.2, C6.2, C7.2, C8.2, C9.2, C10.2, C11.2, C12.2, C13.2, C14.1, C15.2, C16.2, C17.2, C18.2, C19.1, C20.2, C21.2, C22.2, C23.2, C24.2, C25.2, C26.2, C27.2, C28.2, C29.2, C30.2, C31.2, C32.2, C33.2, C34.2, C35.2, C36.1, C37.2, C38.2, C39.2, C40.2, C41.2, C42.2, C43.2, C44.2, C45.2, C46.2, C47.2, D2.1 (K), D5.1 (K), D7.1 (K), D8.1 (K), D9.1 (K), D11.3, J1.6, J2.6, J3.7, J5.10, J6.6, J7.4, J8.10, J9.5, J9.6, J10.4, J11.4, J12.6, J13.10, J14.3, J15.6, J16.3, J17.3, Q1.3 (E), Q2.3 (E), R6.2, R11.2, R20.2, R22.2, R27.2, SW3.1, U1.6 (GND), U1.7 (RESV_7), U1.11 (RESV_11), U2.10 (VSS), U2.19 (VSSA), U2.26 (VSS), U2.49 (VSS), U2.74 (VSS), U2.99 (VSS), U3.3 (VSS), U3.6 (SDO/AD0), U3.8 (RESV), U3.9 (RESV), U4.8 (VSSA), U4.23 (VSS), U4.35 (VSS), U4.47 (VSS), U5.A5 (CSB), U5.C1 (SDO), U5.C5 (GND), U5.E1 (GND), U5.E3 (GND), U6.1 (GND), U7.6 (GNDIO), U7.7 (GND), U8.2 (GND), U9.2 (GND), U9.8 (Rs), U10.4 (GND), U11.2 (GND), Y1.2 (G), Y1.4 (G), Y2.2 (G), Y2.4 (G)
unnamed: C8.1, R1.1, R5.2
unnamed: C26.1, R15.1, Y2.3
unnamed: C37.1, R29.1, Y1.3
unnamed: C10.1, D1.1 (K), D3.1 (K), U8.1 (IN), U8.3 (EN)
unnamed: D2.2 (A), R32.2
unnamed: D4.1 (K), R6.1
unnamed: D5.2 (A), R33.2
unnamed: D7.2 (A), R35.2
unnamed: D8.2 (A), R36.2
unnamed: D9.2 (A), R37.2
unnamed: D11.2, J7.2, R5.1, U9.7 (CANH)
unnamed: D11.1, J7.3, R1.2, U9.6 (CANL)
unnamed: J16.2, Q2.2 (B)
unnamed: Q1.2 (B), R31.2
unnamed: R12.1, SW4.2
unnamed: C21.1, U2.12 (PH0), Y2.1
unnamed: R15.2, U2.13 (PH1)
unnamed: C25.1, U2.48 (VCAP_1)
unnamed: C28.1, U2.73 (VCAP_2)
unnamed: C14.2, R25.2, U4.7 (NRST)
unnamed: C38.1, U4.5 (PD0), Y1.1
unnamed: R29.2, U4.6 (PD1)
unnamed: R39.2, R40.2, U9.5 (Vref)
unnamed: R17.2, U10.3 (~WP/IO_{2})
